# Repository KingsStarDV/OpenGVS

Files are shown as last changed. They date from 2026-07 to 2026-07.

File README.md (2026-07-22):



# SAFETY WARNING [Read This First]
## ⚠️ Safety

OpenGVS applies a small amount of current across the mastoid (behind the ears) to stimulate the vestibular system. You are requied to read this before continuing:

**Dont Use OPENGVS or Similar Device if You::**
- Have a pacemaker, cochlear implant, or any other implanted electronic medical device
- Have epilepsy or a history of seizures
- Have any diagnosed neurological or inner-ear condition (e.g. vestibular disorders, Ménière's disease)

**Before first use:**
- Verify the output current with a multimeter — don't rely on the calculated value alone. Check if it stays within the limit before using it on skin.
- Double Check for the connections.. Any faulty connection in any of the circuit can result in flow of more current than safe.
- Test on a dummy load (for eg. a Resistor of 10k OHM)

**General:**
This is a open source Project and is not cerfitied as a medical device.. Use it with caution and at you own risk.
If you are unclear whether to use this or not, consult a doctor first..

ALSO dont use it near stairs, machineries, water or anyplace where falling can cause major injuries..

# What is a GVS ?

Simply speaking, GVS is a device which can ***HACK*** your balance. (i.e. your bodies tendency to shift either left or right to keep itself upright)

It does this by applying a **very little** current through a specific part of your head that contains the organs which sense the orientation of the body (i.e. vestibular system)

# How OPENGVS Works !

To control the balance of body we need to send **very little** current through our mastoids (i.e. the bony part right behind the ears)
This makes the current to interfere with the vestibular system and then *hack* our balance..

****BUT**** we dont want to send a lot of current through our head and fry our brain.
So the current must be limited to a **MAX OF 4mA**.

This is done through using a "current sense feedback loop". [More on this later]

I also wanted the current to be able to flow both from left to right and from right to left.
So i used a H bridge, to do so..

Thw complete thing is powered through a single 18650 cell of 3.7v

To make it wireless i decided to add a ESP32C3-Mini.

When the right firmware is uploaded in the ESP32, it starts a WiFi and theen connected to the Wifi, we meet with a webpage from where we can control wheter we want the current to flow from right to left or from left to right. (in other words i can control wheter the user moves left or right through the web page)

# The Assembly Instructions

### First of all solder the H bridge on a perf Board [or you can use a breadboard or get a PCB-- I will use a perfboard]



This is the Schematic for the H bridge.
The H bridge is pretty simple. 

The pins A, B will be connected to GPIO pins 7 & 8 of Esp32.
Pulling these pins High of Low decides the direction of the current..
The GND is connected to OFCOURSE the GND.

HOLD THE CCV pins for now..

#### Second- Solder the Current Limiting Circuit As per the Schematic.

The circuit of the bottom left of the image..

This circuits works as follow-

The transistor Q7 starts to conduct current to the pin CCV, but when a certain threshold current goes through the 220ohm resistor to Q7, the resistor creates a potential difference across it.
This potential difference is falt directly across the Base and emitter pin of the Q9.
This makes the Q9 to conduct and thus it drian all the curent to gnd..
Hence the current is limited to a certain limit through the resistor.

In this case its 3.2mA MAX.

#### Third- Add the ESP32 and battery and Volage Converters.


this is the final connection..

You can alter this last step according to your need.
the multiple mounting holes in the schematic are for only the purpose of converting 3.7v into 3.3v, nd 12v for the esp32 and H bridge to work.

# Flashing Firmware :
Flshing firmware is easiest part of this build..
Just donwload the firmware given in this repo in any compiler that you use [reccomended: Arduino IDE]
[These next steps are different for every IDE, i m using ARDUINO IDE]

then click FILES then PREFRENCES.
In "Additional Boards Manager URLs" add:

```
https://raw.githubusercontent.com/espressif/arduino-esp32/gh-pages/package_esp32_index.json
```
Then Click TOOLS, then BOARDS, then BOARD MANAGER.
Search "esp32" and install the package by Espressif Systems

NEXT, connect the esp32 c3 and in TOOLS > BAORD search and select Esp32 C3 Mini...

FInally Upload the code.
# BOM

# Bill of Materials (BOM)

## 🔌 Boards & Prototyping
| Component | Short Name | Qty | Unit Price (INR) | Subtotal (INR) | Source | Link |
|---|---|---|---|---|---|---|
| VeroBoard (6x4 Inch) | Perfboard 6x4" | 1 | 40.00 | 40.00 | Robocraze | https://robocraze.com/products/veroboard6x4?_pos=2&_sid=71be420dd&_ss=r |
| ESP32-C3 Mini Development Board - Unsoldered | ESP32-C3 Dev Board | 1 | 234.00 | 234.00 | Robocraze | https://robocraze.com/products/esp32-c3-mini-development-board-unsoldered?variant=48465411506400 |

## 🔋 Power & Charging
| Component | Short Name | Qty | Unit Price (INR) | Subtotal (INR) | Source | Link |
|---|---|---|---|---|---|---|
| TP4056 1A Li-ion Charging Module (Type-C, w/ protection) | TP4056 Li-ion Charger | 1 | 16.00 | 16.00 | Makerbazar | https://makerbazar.in/products/tp4056-1a-li-ion-lithium-battery-charging-module?variant=45459125567728 |
| 18650 SMD/SMT Battery Holder Case (Single) | 18650 Battery Holder | 1 | 39.00 | 39.00 | Makerbazar | https://makerbazar.in/products/18650-battery-holder-single-battery.js?variant=44006735 |
| Samsung SDI INR18650 Li-Ion Rechargeable Cell, 3000mAh | 18650 Li-ion Cell (3000mAh) | 1 | 249.00 | 249.00 | Makerbazar | https://makerbazar.in/products/samsung-sdi-inr18650-li-ion-rechargeable-cells?variant=48251034140912 |

## ⚡ DC-DC Converters
| Component | Short Name | Qty | Unit Price (INR) | Subtotal (INR) | Source | Link |
|---|---|---|---|---|---|---|
| DC-DC 1.8V-5V to 3.3V Booster/Buck Module | 3.3V DC-DC Converter | 1 | 52.00 | 52.00 | Robu.in | https://robu.in/product/dc-dc-1-8v-5v-to-3-3v-boost-and-buck-power-module/ |
| 3.7V to 12V Mini DC-DC Boost Step-Up Converter (5V/8V/9V/12V out) | 3.7V-12V DC-DC Boost Converter | 1 | 18.00 | 18.00 | Robu.in | https://robu.in/product/3-7v-to-12v-mini-dc-dc-boost-step-up-converter-board-module-5v-8v-9v-12v-output/ |

## 🔺 Transistors & MOSFETs
| Component | Short Name | Qty | Unit Price (INR) | Subtotal (INR) | Source | Link |
|---|---|---|---|---|---|---|
| IRLZ44N MOSFET, DIP-3 | IRLZ44N MOSFET (N-Ch) | 2 | 39.00 | 78.00 | Robu.in | https://robu.in/product/irlz44n/ |
| SPP18P06PHXKSA1 Infineon Power MOSFET, P-Ch, 60V, 18.7A, TO-220 | SPP18P06 MOSFET (P-Ch) | 2 | 180.00 | 360.00 | Robu.in | https://robu.in/product/spp18p06phxksa1-infineon-power-mosfet-p-channel/ |
| 2N3904 NPN Transistor, TO-92, onsemi | 2N3904 NPN Transistor | 2 | 18.00 | 36.00 | Robu.in | https://robu.in/product/2n3904ta-onsemi-40v-625mw-400-1ma1-0v-200ma-npn-to-92-3l-bipolar-bjt-rohs/ |
| 2N3906 PNP Transistor, TO-92, JCET | 2N3906 PNP Transistor | 2 | 5.00 | 10.00 | Robu.in | https://robu.in/product/2n3906-ta-jcet-40v-625mw-10010ma1v-200ma-pnp-to-92-bipolar-bjt-rohs/ |

## 🧩 Passive Components (Local)
| Component | Short Name | Qty | Unit Price (INR) | Subtotal (INR) | Source | Link |
|---|---|---|---|---|---|---|
| Electrode | Electrode | 2 | 15.00 | 30.00 | Local Market | N/A - local purchase |
| Resistor 220 Ohm | 220R Resistor | 1 | 10.00 | 10.00 | Local Market | N/A - local purchase |
| Resistor 10K Ohm | 10K Resistor | 5 | 10.00 | 50.00 | Local Market | N/A - local purchase |

---
**Grand Total:** ₹1,222.00
So thats all...............

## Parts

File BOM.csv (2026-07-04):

Category | Component | Short Name | Quantity | Unit Price (INR) | Subtotal (INR) | Source | Link
Boards & Prototyping | VeroBoard (6x4 Inch) | Perfboard 6x4in | 1 | 40 | 40 | Robocraze | https://robocraze.com/products/veroboard6x4?_pos=2&_sid=71be420dd&_ss=r
Boards & Prototyping | ESP32-C3 Mini Development Board - Unsoldered | ESP32-C3 Dev Board | 1 | 234 | 234 | Robocraze | https://robocraze.com/products/esp32-c3-mini-development-board-unsoldered?variant=48465411506400
Power & Charging | TP4056 1A Li-ion Charging Module (Type-C w/ protection) | TP4056 Li-ion Charger | 1 | 16 | 16 | Makerbazar | https://makerbazar.in/products/tp4056-1a-li-ion-lithium-battery-charging-module?variant=45459125567728
Power & Charging | 18650 SMD/SMT Battery Holder Case (Single) | 18650 Battery Holder | 1 | 39 | 39 | Makerbazar | https://makerbazar.in/products/18650-battery-holder-single-battery.js?variant=44006735
Power & Charging | Samsung SDI INR18650 Li-Ion Rechargeable Cell 3000mAh | 18650 Li-ion Cell (3000mAh) | 1 | 249 | 249 | Makerbazar | https://makerbazar.in/products/samsung-sdi-inr18650-li-ion-rechargeable-cells?variant=48251034140912
DC-DC Converters | DC-DC 1.8V-5V to 3.3V Booster/Buck Module | 3.3V DC-DC Converter | 1 | 52 | 52 | Robu.in | https://robu.in/product/dc-dc-1-8v-5v-to-3-3v-boost-and-buck-power-module/
DC-DC Converters | 3.7V to 12V Mini DC-DC Boost Step-Up Converter (5V/8V/9V/12V out) | 3.7V-12V DC-DC Boost Converter | 1 | 18 | 18 | Robu.in | https://robu.in/product/3-7v-to-12v-mini-dc-dc-boost-step-up-converter-board-module-5v-8v-9v-12v-output/
Transistors & MOSFETs | IRLZ44N MOSFET DIP-3 | IRLZ44N MOSFET (N-Ch) | 2 | 39 | 78 | Robu.in | https://robu.in/product/irlz44n/
Transistors & MOSFETs | SPP18P06PHXKSA1 Infineon Power MOSFET P-Ch 60V 18.7A TO-220 | SPP18P06 MOSFET (P-Ch) | 2 | 180 | 360 | Robu.in | https://robu.in/product/spp18p06phxksa1-infineon-power-mosfet-p-channel/
Transistors & MOSFETs | 2N3904 NPN Transistor TO-92 onsemi | 2N3904 NPN Transistor | 2 | 18 | 36 | Robu.in | https://robu.in/product/2n3904ta-onsemi-40v-625mw-400-1ma1-0v-200ma-npn-to-92-3l-bipolar-bjt-rohs/
Transistors & MOSFETs | 2N3906 PNP Transistor TO-92 JCET | 2N3906 PNP Transistor | 2 | 5 | 10 | Robu.in | https://robu.in/product/2n3906-ta-jcet-40v-625mw-10010ma1v-200ma-pnp-to-92-bipolar-bjt-rohs/
Passive Components (Local) | Electrode | Electrode | 2 | 15 | 30 | Local Market | N/A - local purchase
Passive Components (Local) | Resistor 220 Ohm | 220R Resistor | 1 | 10 | 10 | Local Market | N/A - local purchase
Passive Components (Local) | Resistor 10K Ohm | 10K Resistor | 5 | 10 | 50 | Local Market | N/A - local purchase

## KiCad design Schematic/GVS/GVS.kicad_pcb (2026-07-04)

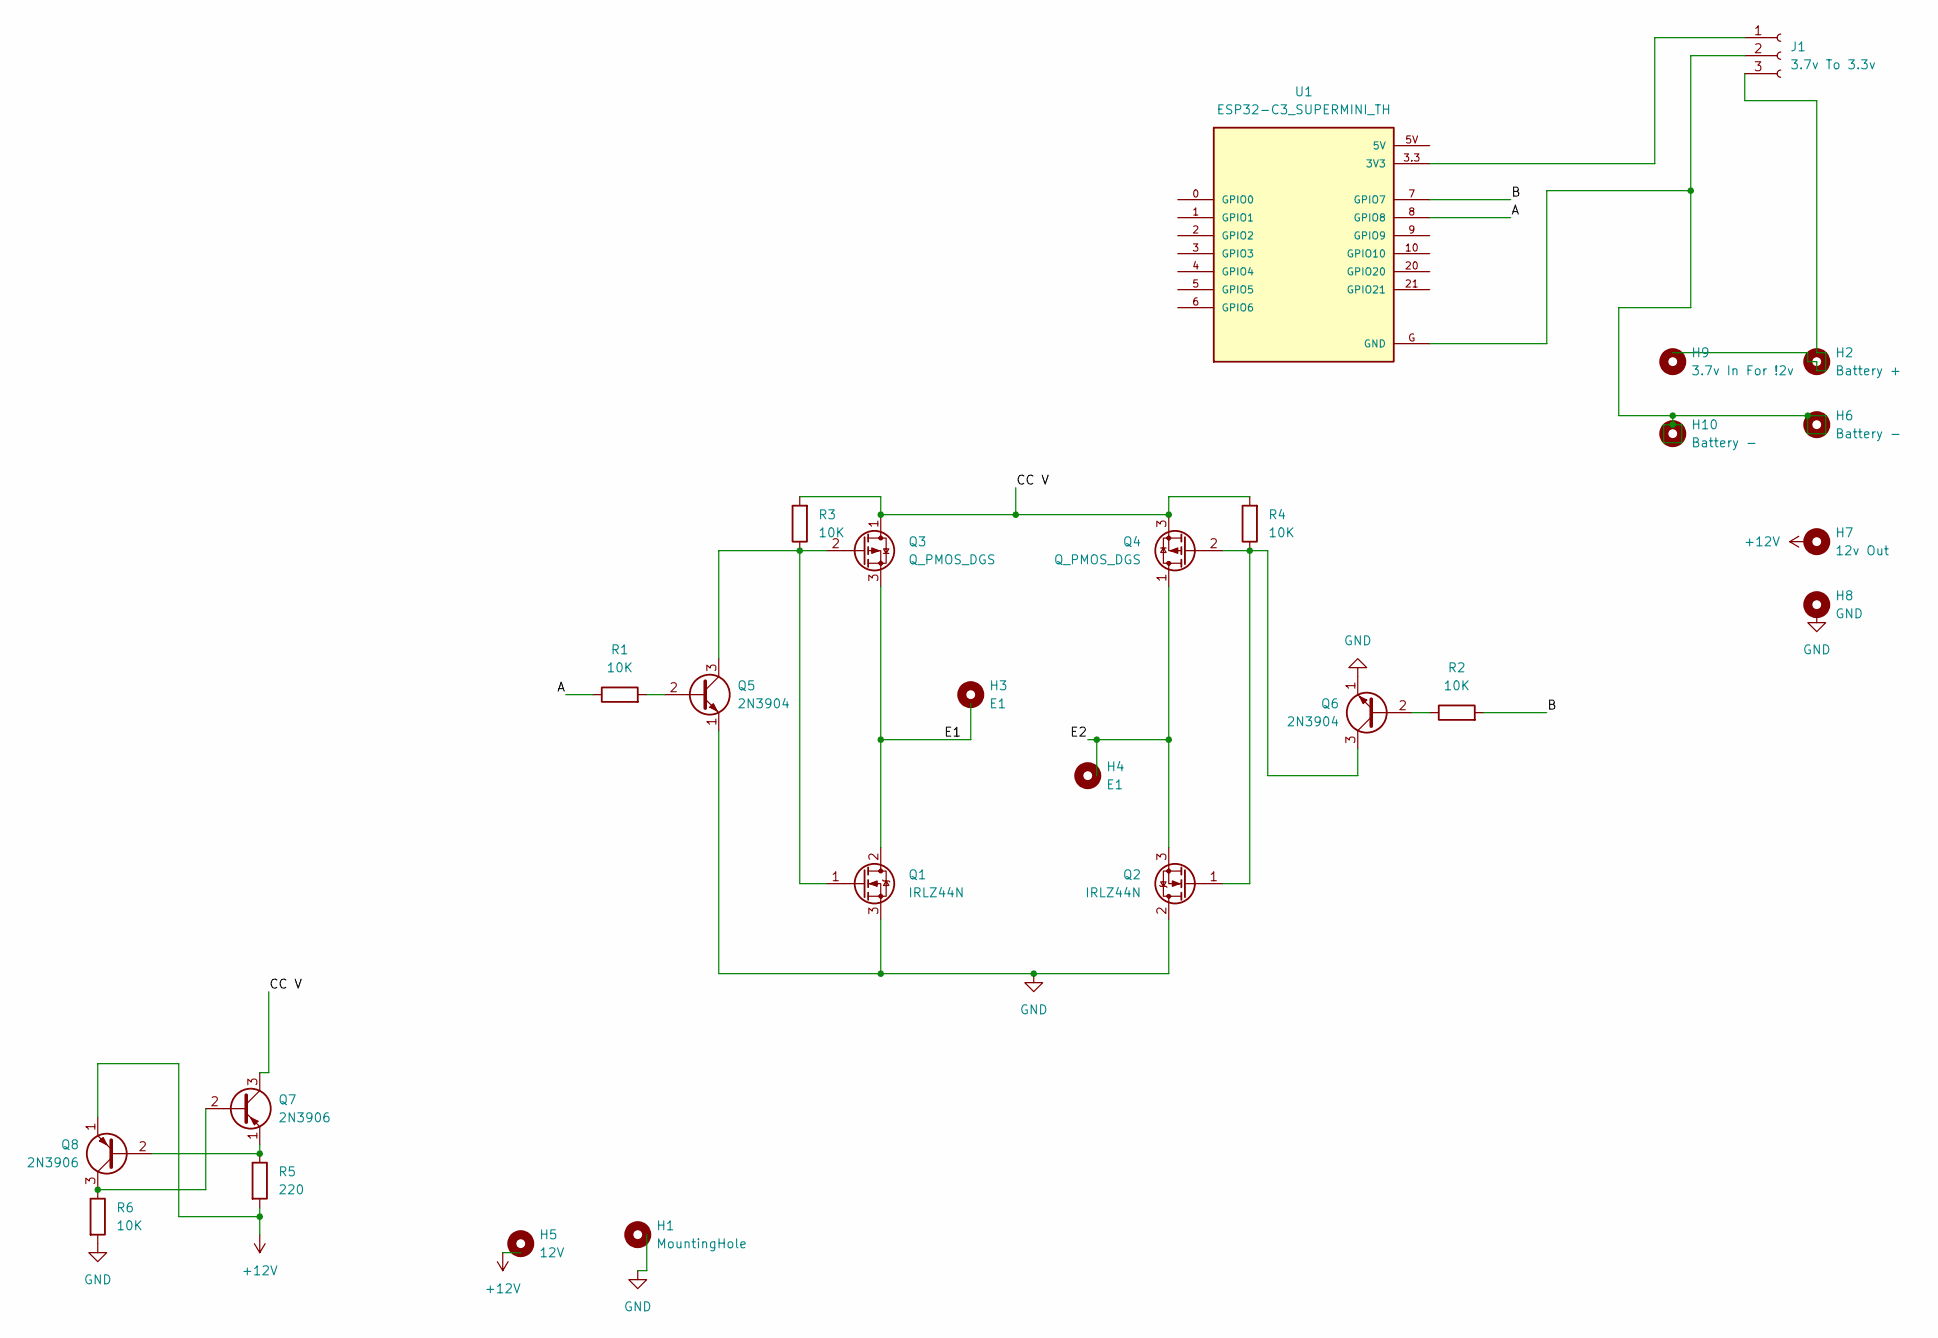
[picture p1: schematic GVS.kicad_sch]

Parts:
H1: MountingHole; MountingHole_2.2mm_M2_DIN965_Pad_TopBottom
H2: Battery +; MountingHole_2.2mm_M2_DIN965_Pad_TopBottom
H3, H4: E1; MountingHole_2.2mm_M2_DIN965_Pad_TopBottom
H5: 12V; MountingHole_2.2mm_M2_DIN965_Pad_TopBottom
H6, H10: Battery -; MountingHole_2.2mm_M2_DIN965_Pad_TopBottom
H7: 12v Out; MountingHole_2.2mm_M2_DIN965_Pad_TopBottom
H8: GND; MountingHole_2.2mm_M2_DIN965_Pad_TopBottom
H9: 3.7v In For !2v; MountingHole_2.2mm_M2_DIN965_Pad_TopBottom
J1: 3.7v To 3.3v; PinHeader_1x03_P2.00mm_Vertical
Q1, Q2: IRLZ44N; TO-220-3_Vertical
Q3, Q4: Q_PMOS_DGS; TO-220-3_Vertical
Q5, Q6: 2N3904; TO-92_Inline
Q7, Q8: 2N3906; TO-92_Inline
R1, R2, R3, R4, R6: 10K; R_Axial_DIN0207_L6.3mm_D2.5mm_P7.62mm_Horizontal
R5: 220; R_Axial_DIN0207_L6.3mm_D2.5mm_P7.62mm_Horizontal
U1: ESP32-C3_SUPERMINI_TH; MODULE_ESP32-C3_SUPERMINI_TH

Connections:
+12V: Q8.1 (E), R5.2
/A: R1.1, U1.8 (GPIO8)
/B: R2.2, U1.7 (GPIO7)
/CC V: Q3.1 (D), Q4.3 (S), Q7.3 (C), R3.2, R4.2
/E1: Q1.2 (D), Q3.3 (S)
/E2: Q2.3 (S), Q4.1 (D)
GND: Q1.3 (S), Q2.2 (D), Q5.1 (E), Q6.1 (E), R6.2
unnamed: J1.1, U1.3.3 (3V3)
unnamed: J1.2, U1.G (GND)
unnamed: Q1.1 (G), Q3.2 (G), Q5.3 (C), R3.1
unnamed: Q2.1 (G), Q4.2 (G), Q6.3 (C), R4.1
unnamed: Q5.2 (B), R1.2
unnamed: Q6.2 (B), R2.1
unnamed: Q7.2 (B), Q8.3 (C), R6.1
unnamed: Q7.1 (E), Q8.2 (B), R5.1

Board: 2 copper layers, 26 parts (0 on the bottom side), 15 nets, no tracks yet.

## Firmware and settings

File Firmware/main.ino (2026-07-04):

#include <WiFi.h>
#include <WebServer.h>

WebServer myserver(80);


const char* ssid = "ESP32";
const char* password = "kings00000";

void setup(){
  Serial.begin(115200);
  WiFi.softAP(ssid, password);
  Serial.println("AP initiated");
  Serial.println(WiFi.softAPIP());

  myserver.on("/", handleRoot);
  myserver.on("/rightOn", handleRightOn);
  myserver.on("/rightOff", handleRightOff);
  myserver.on("/leftOn", handleLeftOn);
  myserver.on("/leftOff", handleLeftOff);
  myserver.begin();
  Serial.println("Server initiated");

  pinMode(7, OUTPUT);
  pinMode(8, OUTPUT);
}

void handleRightOn(){
  digitalWrite(8, HIGH);
  myserver.send(200, "text/plain", "OK");
}

void handleRightOff(){
  digitalWrite(8, LOW);
  myserver.send(200, "text/plain", "OK");
}

void handleLeftOn(){
  digitalWrite(7, HIGH);
  myserver.send(200, "text/plain", "OK");
}

void handleLeftOff(){
  digitalWrite(7, LOW);
  myserver.send(200, "text/plain", "OK");
}


void handleRoot(){
  myserver.send(200, "text/html", R"HTMLCODE(
    <!DOCTYPE html>
    <html>
    <body>
    <button onmousedown="rightPressed()" onmouseup="rightLifted()"> RIGHT </button>
    <button onmousedown="leftPressed()" onmouseup="leftLifted()"> LEFT </button>

    <script>
function rightPressed() {
  fetch("/rightOn");
}
function rightLifted() {
  fetch("/rightOff");
}
function leftPressed() {
  fetch("/leftOn");
}
function leftLifted() {
  fetch("/leftOff");
}
</script>
    </body>
    </html>
  )HTMLCODE");
}


void loop(){
  myserver.handleClient();
}
